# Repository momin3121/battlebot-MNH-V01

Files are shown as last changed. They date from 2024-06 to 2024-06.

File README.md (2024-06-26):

# battlebot-MNH-V01

## Table of Contents
1. [Introduction](#introduction)
2. [Design Overview](#design-overview)
3. [Weight and Dimensions](#weight-and-dimensions)
4. [Frame Construction](#frame-construction)
5. [tool System](#tool-system)
6. [Electrical Components](#electrical-components)
7. [PCB Design](#pcb-design)
8. [References](#references)

## Introduction
The "battlebot-MNH-V01" is a custom-built battle bot designed for high performance in competitive environments. This bot combines precision engineering and robust construction to achieve high mobility and effective combat capabilities.

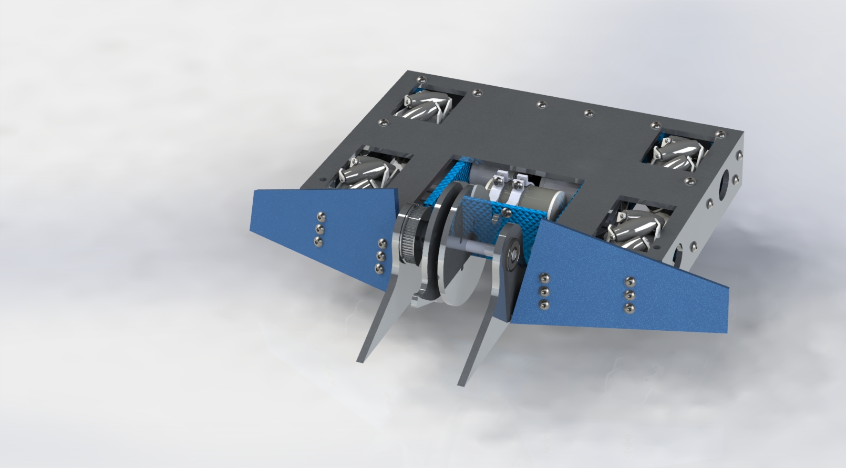
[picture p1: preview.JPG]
Battle Bot


## Design Overview
### Frame Construction
- **Material:** Aluminum
- **Construction:** The frame serves as the skeleton, providing a sturdy yet lightweight base. It includes reinforcements at critical stress points to prevent deformation during combat.
- **Benefits:** The use of aluminum and 3D-printed components allows for rapid prototyping and customization, ensuring flexibility and cost-effectiveness.

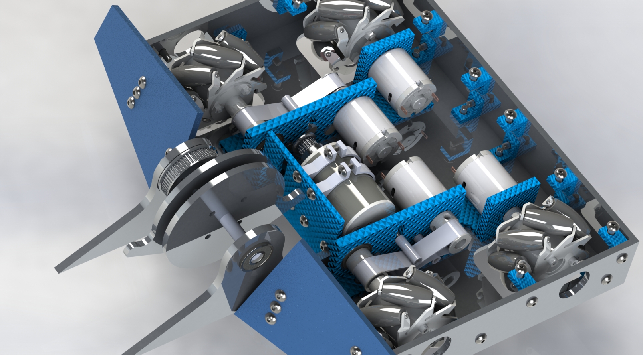
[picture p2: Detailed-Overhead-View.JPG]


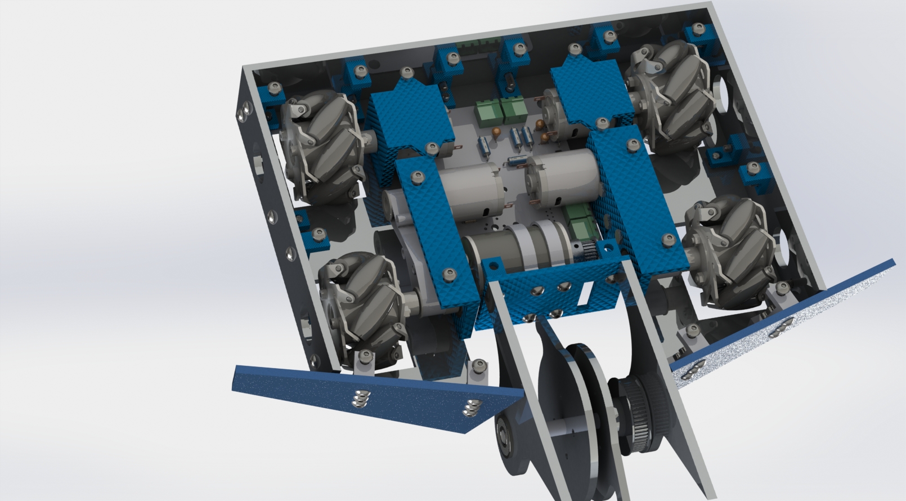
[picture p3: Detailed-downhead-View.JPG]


### Weight and Dimensions
- **Total Weight:** 3 kg
- **Overall Dimensions:** 21 cm x 20 cm

## Tool System
### Integration
- **Primary Weapon:** A centrally mounted spinning blade made from hardened steel.
- **Motor:** High-torque electric motor.
- **Specifications:**
  - **Spin Rate:** Up to 5000 RPM
  - **Impact Resistance:** Designed for high durability and easy field repairs.

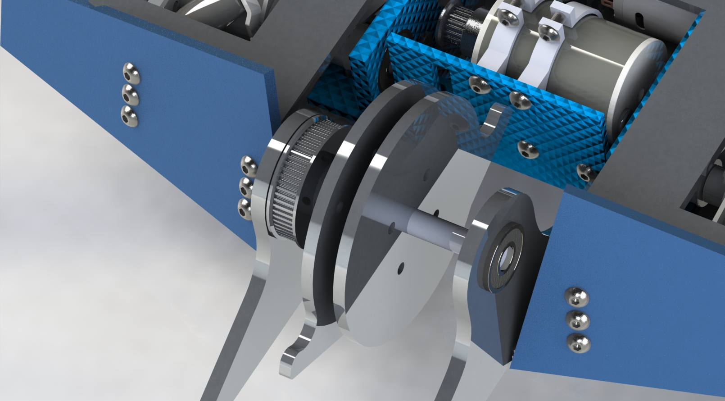
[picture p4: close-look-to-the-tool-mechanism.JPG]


## Electrical Components
### Key Components
- **DC Motor:** High Speed Electric Brush Motor (12V, 100W, 5000RPM)
- **Transmitter:** GoolRC Flysky FS-i6X Transmitter with FS-iA6B Receiver
- **Battery:** CNHL 2200mAh 3S Lipo Battery (30C, 11.1V)
- **Wheels:** Premium 97mm Mecanum Wheels
- **Controller:** ESP32-PICO-D4 microcontroller for managing motor and sensor inputs.

### Motor Drivers
- **Wheel Motors:** Dual L298HN Motor Drivers
- **Weapon Motor:** VNH2SP30 Motor Driver

## PCB Design
### Overview
The PCB (Printed Circuit Board) for the battle bot is designed to control all major functions, including motor control and sensor integration. The design focuses on robustness, efficiency, and ease of maintenance, ensuring optimal performance during competitions.

### Size and Layers
- **Dimensions:** 10 cm x 9.5 cm
- **Layers:** 2-layer design for efficient routing of power and signal traces.

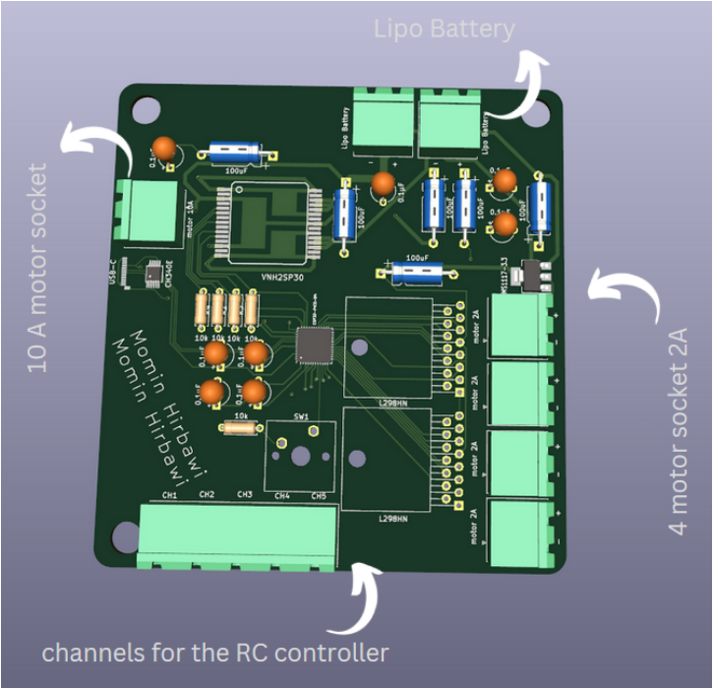
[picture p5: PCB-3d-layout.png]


### Trace Widths
- **Motor Traces:** 0.8 mm (for currents up to 2A)
- **Tool  Motor Traces:** 2.5 mm (for currents up to 10A)
- **Design Standards:** Trace widths are calculated based on IPC-2221 standards to handle the expected current loads with an allowable temperature rise of 10°C to 20°C.

### Key Components
- **Microcontroller (U3):** ESP32-PICO-D4
  - **Function:** Central processing unit that handles control logic, motor commands, and sensor inputs.
  - **Power Supply:** 3.3V provided by AMS1117-3.3 voltage regulator.
- **Motor Drivers:**
  - **L298HN (U1, U5):** Controls the four wheel motors, allowing precise movement and speed adjustments.
  - **VNH2SP30 (U2):** Manages the high-current weapon motor, providing necessary torque and speed.
- **Voltage Regulator (U6):** AMS1117-3.3
  - **Function:** Provides stable 3.3V output for low-power devices.
  - **Current Handling:** Up to 1A, supporting the microcontroller and sensors.
- **USB to Serial Converter (U4):** CH340E
  - **Function:** Enables programming and communication between the microcontroller and a computer.
- **Capacitors (C1, C10-C16):** Stabilize voltage and filter noise in the power supply.
- **Resistors (R1, R2, R3, R4, R6):** Employed for pulling up/down inputs and limiting current to protect other components.
- **Connectors (J1, J2, J3, J4, J5, J6):** Provide interfaces for external connections to motors, power sources, and other peripherals.
- **Switch (SW1):** Used to enable the microcontroller, typically controlling the power state or activation of the system.

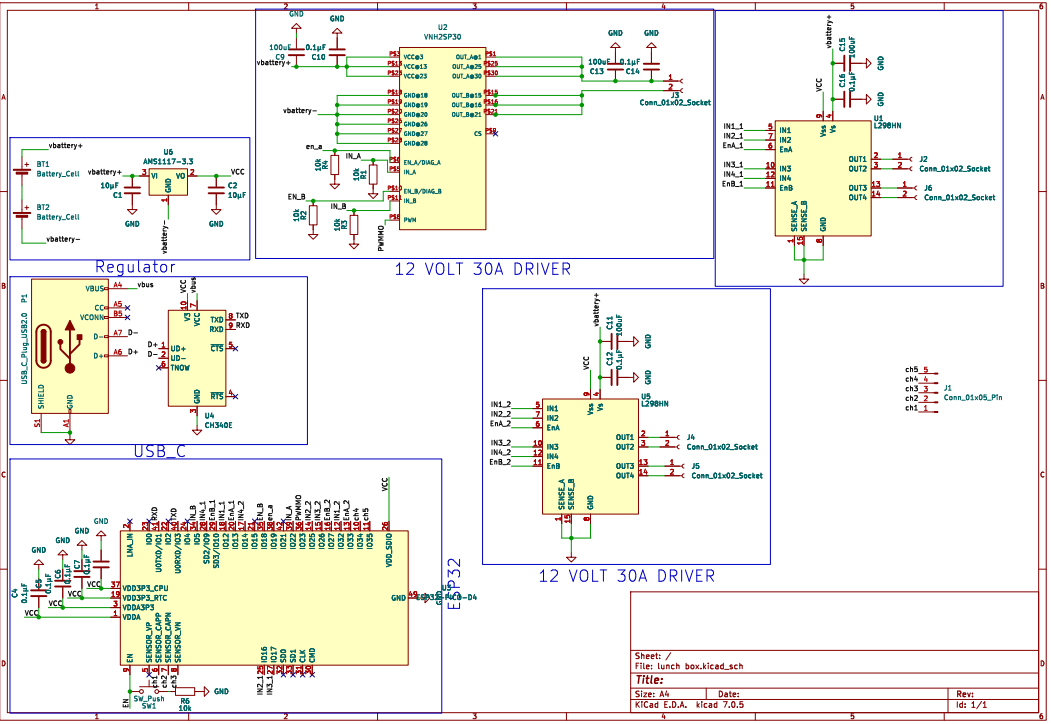
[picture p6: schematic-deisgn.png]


### Power Management
- **AMS1117-3.3 Voltage Regulator (U6):**
  - **Function:** Provides a stable 3.3V output for low-power devices.
  - **Current Handling:** Up to 1A.
  - **Integration:** Positioned near power inputs with filtering capacitors to ensure smooth operation.
- **VNH2SP30 Motor Driver:**
  - **Function:** Drives the weapon motor.
  - **Current Handling:** 30A continuous.
  - **Integration:** Includes extensive heat sinking to manage high current loads.
- **Dual L298HN Motor Drivers:**
  - **Function:** Independently controls four wheel motors.
  - **Current Handling:** 2A per channel.
  - **Integration:** Equipped with dedicated capacitors for voltage stabilization and noise filtering.

### Layout and Design Considerations
- **Trace Width:** Motor traces are designed to handle high currents without excessive heat buildup or voltage drop.
- **Via Optimization:** Used to connect traces between the top and bottom layers, enhancing electrical performance.
- **Accessibility:** All connectors and critical components are easily accessible for maintenance and troubleshooting.

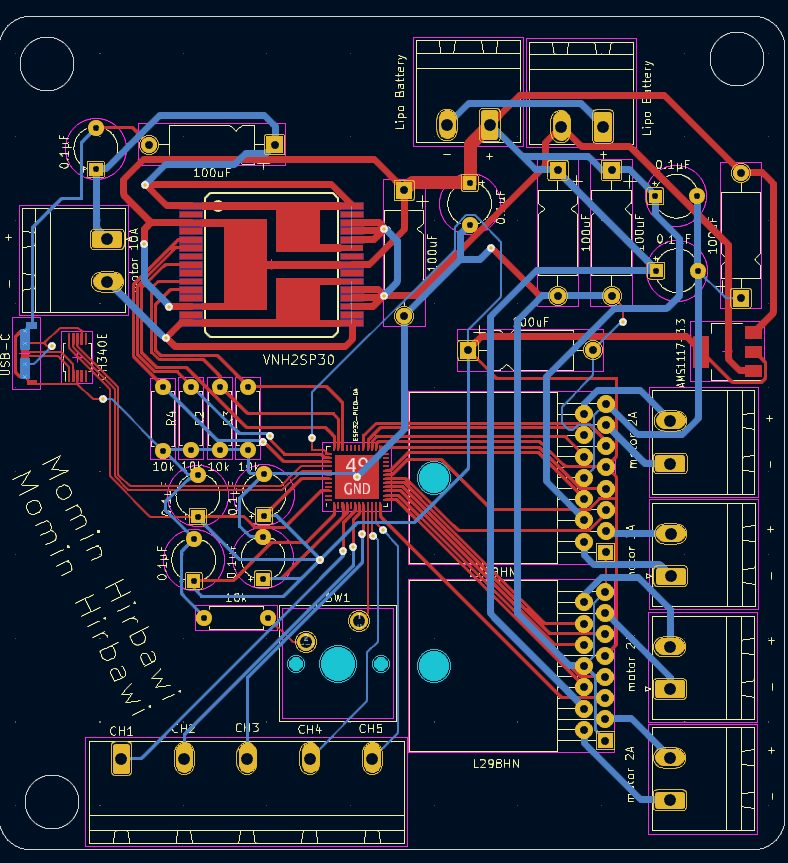
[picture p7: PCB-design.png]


## Code Example
```cpp
#include <ESP32Servo.h>
#include <FlySkyIBus.h>

const int enA1Pin = 13; 
const int in1_1Pin = 12;
const int in2_1Pin = 16;
const int enB1Pin = 10; 
const int in3_1Pin = 17;
const int in4_1Pin = 9;

const int enA2Pin = 33; 
const int in1_2Pin = 32;
const int in2_2Pin = 25;
const int enB2Pin = 27; 
const int in3_2Pin = 26;
const int in4_2Pin = 14;

const int enBPin = 35; 
const int inBPin = 5;
const int inAPin = 22;
const int pwmPin = 23;  

const int gunMotorPin = 19; 

const int enableSwitchPin = 9;

const int pwmFreq = 5000;
const int pwmResolution = 8;

const int ch1 = 0; 
const int ch2 = 1; 
const int ch3 = 2; 
const int ch4 = 3; 
const int ch5 = 4; 

void setup() {
  Serial.begin(115200);
  IBus.begin(Serial1, 115200);
  
  ledcSetup(0, pwmFreq, pwmResolution);
  ledcSetup(1, pwmFreq, pwmResolution);
  ledcSetup(2, pwmFreq, pwmResolution);
  ledcSetup(3, pwmFreq, pwmResolution);
  ledcSetup(4, pwmFreq, pwmResolution);
  ledcSetup(5, pwmFreq, pwmResolution);
  ledcSetup(6, pwmFreq, pwmResolution);

  ledcAttachPin(enA1Pin, 0);
  ledcAttachPin(enB1Pin, 1);
  ledcAttachPin(enA2Pin, 2);
  ledcAttachPin(enB2Pin, 3);
  ledcAttachPin(gunMotorPin, 4);
  ledcAttachPin(pwmPin, 5);

  pinMode(in1_1Pin, OUTPUT);
  pinMode(in2_1Pin, OUTPUT);
  pinMode(in3_1Pin, OUTPUT);
  pinMode(in4_1Pin, OUTPUT);
  pinMode(in1_2Pin, OUTPUT);
  pinMode(in2_2Pin, OUTPUT);
  pinMode(in3_2Pin, OUTPUT);
  pinMode(in4_2Pin, OUTPUT);
  pinMode(inBPin, OUTPUT);
  pinMode(inAPin, OUTPUT);
  
  pinMode(enableSwitchPin, INPUT);
}

void loop() {
  bool isEnabled = digitalRead(enableSwitchPin);

  if (isEnabled) {
    int throttle = IBus.readChannel(ch1);
    int steering = IBus.readChannel(ch2);
    int strafe = IBus.readChannel(ch3);
    int rotation = IBus.readChannel(ch4);
    int gunControl = IBus.readChannel(ch5);

    throttle = map(throttle, 1000, 2000, -255, 255);
    steering = map(steering, 1000, 2000, -255, 255);
    strafe = map(strafe, 1000, 2000, -255, 255);
    rotation = map(rotation, 1000, 2000, -255, 255);
    gunControl = map(gunControl, 1000, 2000, 0, 255);

    int motor1Speed = throttle + steering + strafe - rotation;
    int motor2Speed = throttle - steering - strafe - rotation;
    int motor3Speed = throttle - steering + strafe + rotation;
    int motor4Speed = throttle + steering - strafe + rotation;

    motor1Speed = constrain(motor1Speed, 0, 255);
    motor2Speed = constrain(motor2Speed, 0, 255);
    motor3Speed = constrain(motor3Speed, 0, 255);
    motor4Speed = constrain(motor4Speed, 0, 255);

    ledcWrite(0, motor1Speed);
    ledcWrite(1, motor2Speed);
    ledcWrite(2, motor3Speed);
    ledcWrite(3, motor4Speed);
    ledcWrite(4, gunControl);
    ledcWrite(5, gunControl);

    digitalWrite(in1_1Pin, motor1Speed > 0);
    digitalWrite(in2_1Pin, motor1Speed < 0);
    digitalWrite(in3_1Pin, motor2Speed > 0);
    digitalWrite(in4_1Pin, motor2Speed < 0);
    digitalWrite(in1_2Pin, motor3Speed > 0);
    digitalWrite(in2_2Pin, motor3Speed < 0);
    digitalWrite(inAPin, gunControl > 0);
    digitalWrite(inBPin, gunControl < 0);

    Serial.print("Throttle: "); Serial.print(throttle);
    Serial.print(" Steering: "); Serial.print(steering);
    Serial.print(" Strafe: "); Serial.print(strafe);
    Serial.print(" Rotation: "); Serial.print(rotation);
    Serial.print(" Gun: "); Serial.println(gunControl);
  } else {
    ledcWrite(0, 0);
    ledcWrite(1, 0);
    ledcWrite(2, 0);
    ledcWrite(3, 0);
    ledcWrite(4, 0);
    ledcWrite(5, 0);
  }

  delay(20);
}
```

## References
1. [High Power DC Motor](https://www.amazon.com/Power-12V-24V-Torque-Bearing-Driver/dp/B086Z47DLJ)
2. [GoolRC Flysky FS-i6X Transmitter](https://www.amazon.com/dp/B0872QHMM3)
3. [CNHL 2200mAh 3S Lipo Battery](https://www.amazon.com/CNHL-2200mAh-Battery-Airplane-Quadcopter/dp/B0BTYPT4RT)
4. [Zeberoxyz GT2 Synchronous Wheel Set](https://www.amazon.com/Zeberoxyz-Synchronous-Aluminum-Timing-20-60T-8B-6/dp/B08QZ4365D)
5. [Premium Mecanum Wheels](https://www.amazon.com/Directional-Coupling-Connector-Raspberry-Microbit/dp/B09KY6C5BG)
6. [VNH2SP30 Motor Driver](https://www.snapeda.com/parts/VNH2SP30-E/STMicroelectronics/view-part/)
7. [L298N Motor Driver](https://www.snapeda.com/parts/L298N/STMicroelectronics/view-part/)
8. [ESP32-PICO-D4 MCU](https://www.snapeda.com/parts/ESP32-PICO-D4/Espressif%20Systems/view-part/)

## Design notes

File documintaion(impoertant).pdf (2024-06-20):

Introduction and Overview

Battle Bot Design Overview

This document outlines the design and features of a custom built battle bot, designed for robust performance in competitive environments. The bot is engineered with precision, focusing on high mobility and effective combat capabilities. Its frame is constructed from high-grade aluminum, chosen for its excellent strength-to-weight ratio, enhancing the bot's agility and impact resilience.

Weight and Dimensions:

- Total Weight: 3 kg
- Material: Aluminum
- Overall Dimensions: 21 cm X 20 cm

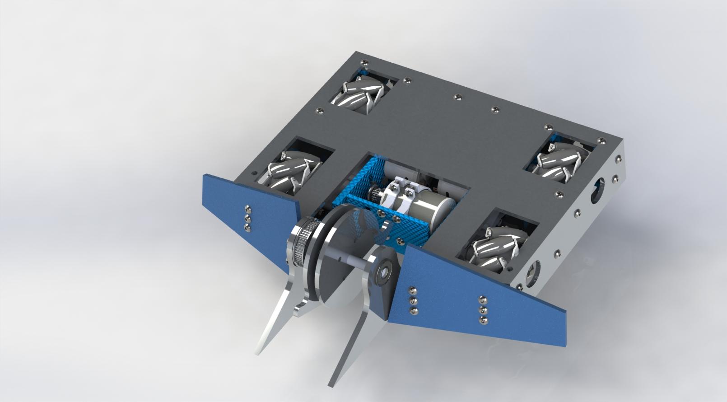
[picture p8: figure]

Frame Construction and Features

Aluminum Frame Construction

The frame of the battle bot serves as the skeleton to which all other components are attached and protected. It is crafted from aluminum, which provides a light yet sturdy base for the operational components and weaponry. The design incorporates a series of reinforcements at critical stress points to prevent deformation under combat conditions.

Materials and Fabrication

- Aluminum Frame: The primary structure is built using aluminum, known for its light weight and high strength, forming the core framework that supports all critical components and systems.
- 3D-Printed Components: Select parts of the battle bot are fabricated using advanced 3D printing technology. Materials such as ABS or PLA are chosen for these parts due to their light weight and ease of printing.

Benefits of Hybrid Construction

- Customization and Flexibility: The ability to quickly produce 3D-printed components allows for rapid prototyping and testing of parts, enabling continuous improvement and customization of the bot.
- Cost-Effective Solutions: Utilizing 3D printing reduces the cost associated with small batch production of complex parts, making it economically viable to design parts that perfectly fit the bot's needs without the need for expensive tooling or molds.

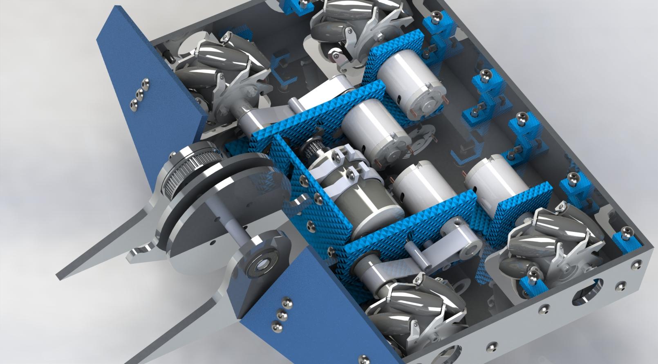
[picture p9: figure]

Figure 2: Detailed Overhead View

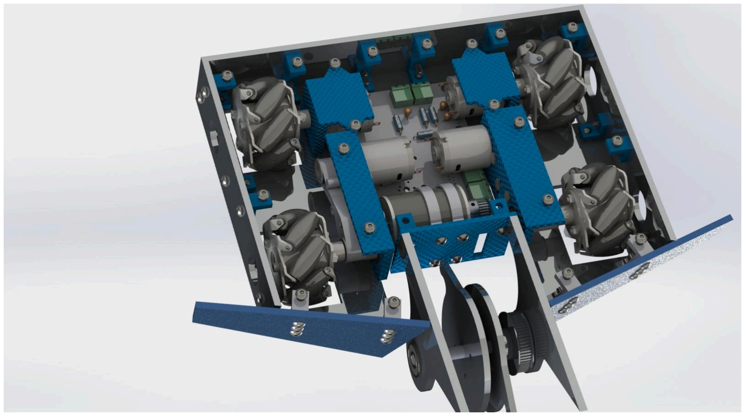
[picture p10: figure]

.Figure 3: Detailed downhead View

Tool System Details

Tool System Integration

The primary weapon system of the battle bot is a centrally mounted spinning blade, designed to deliver high-impact hits to opponents. This weapon is powered by a dedicated motor, with the blade assembly made from hardened steel to withstand the rigors of combat.

Tool Specifications:

1. Blade Material: Hardened steel
2. Motor Type: High-torque electric motor capable of rapid acceleration to maximum speed within seconds.
3. Mounting: The blade is mounted on a reinforced axle connected directly to the motor, with shock-absorbing materials used to reduce vibration and stress on the motor bearings.

Operational Capabilities:

- Spin Rate: Capable of reaching speeds up to 5000 RPM.
- Impact Resistance: Engineered to maintain functionality even after significant impacts, with easy-access features for quick field repairs.

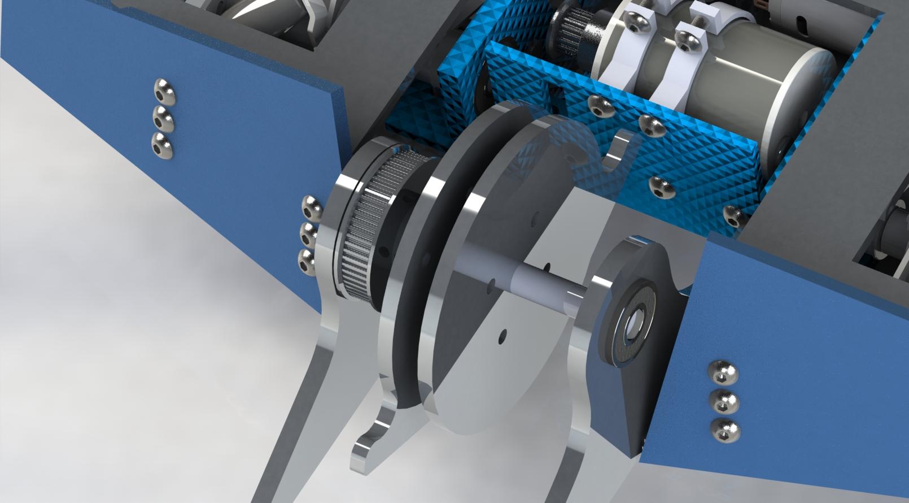
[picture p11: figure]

.Figure 4: close look to the tool mechanism

Electrical component :

The links of every component i will mention will be on the references , plus this is not the PCB components , this is just hard electrical components like motors , controller , etc …

Component | Description | Quantity | Unit Price | Total Price
DC Motor High Speed Electric Brush | 12V 100W Motor 5000RPM High Speed Electric Brush Scooter Motor R6493 RC Car | 1 | $57.39 | $57.3 9
775 High Power DC Motor | DC 12V-24V, 3200 RPM, Large Torque Motor Ball Bearing | 4 | $16.32 | $60
GoolRC Flysky FS-i6X Transmitter | 2.4GHz 10CH AFHDS 2A RC Transmitter with FS-iA6B Receiver | 1 | $46.99 | $16.0 0
CNHL 2200mAh 3S Lipo Battery | 30C 11.1V with Dean Plug, Pack of 2 | 1 | $55.00 | $55.0 0

Premium 97mm Mecanum Wheel | Omni Directional Tire with Metal 6mm Coupling | 1 Set | $43.99 | $43.9 9
Zeberoxyz GT2 Synchronous Wheel Set | 20&60 Teeth 8mm Bore with 200mm Width 6mm Belt | 1 Set | $12.89 | $12.8 9
150g 3D Printed PLA Plastic | Material for custom parts | 150g | $9.40 | $9.40
2.300 kg Aluminum Material | For structural components | 2.300 kg | $76 | $76

Table 1 : components

The PCB Design

Overview

This PCB i made is supposed to control the battle bot completely using the FS-i6X controller , by using driver ic’s for controlling the 5 motors , while the 4 wheels motors should be slower and with a less torque than the weapon motor , so i decided to use 2A DC motor for the wheels and 10A dc motor for the weapon motor , controlled by the main MUC that is (Esp32 - Peco-D4) this esp is supposed to take the signals from the 5 channels from the controller and then convert to a PWM signals to use them with the drivers

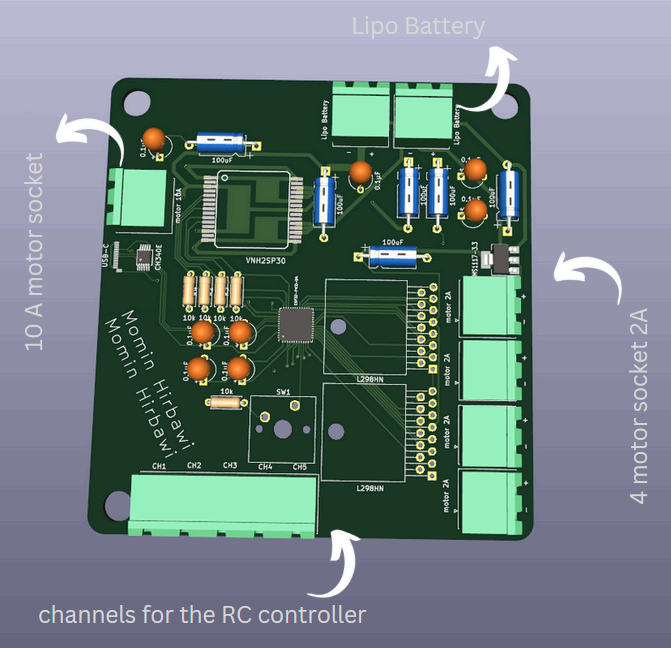
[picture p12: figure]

.Figure 5: PCB 3d layouy

Components and connections

Here is the components and its Function in this Project and the main pins wiring , also you can check the schematic design for more understanding , components in table 1 , and schematic design in figure 6

Component | Descriptio n | Function in Project | Main Pins
U3 (ESP32-PIC O-D4) | Microcontro ller | Central processing unit that handles control logic, motor commands, and sensor inputs. | VDDA, IO34-IO35, IO32-IO33, GND, additional IO pins for sensor and actuator control
U1, U5 (L298HN) | Motor Driver | Controls the four wheel motors, allowing precise movement and speed adjustments. | IN1, IN2, IN3, IN4, EnA, EnB, OUT1, OUT2, OUT3, OUT4, Vs, Vss
U2 (VNH2SP30) | Motor Driver | Manages the high-current weapon motor, providing necessary torque and speed. | IN_A, IN_B, PWM, CS, OUT_A, OUT_B, VCC, GND
U6 (AMS1117-3. 3) | Voltage Regulator | Supplies a stable 3.3V power to low-power components on the board. | VI (Input Voltage), VO (Output Voltage), GND
U4 (CH340E) | USB to Serial Converter | Enables programming and communication between the microcontroller and a computer. | TXD, RXD, VCC, GND, D+, D-, UD+
C1, C10-C16 | Capacitors | Stabilize voltage and filter noise in the power supply to various components. | - (Connected across power and ground pins of associated components)
R1, R2, R3, R4, R6 | Resistors | Employed for pulling up/down inputs and limiting current to protect other components. | - (Connected in line or across signals and power for biasing and protection)
J1, J2, J3, J4, J5, J6 | Connectors | Provide interfaces for external connections to motors, power sources, and other peripherals. | - (Pin numbers vary by connector type and usage in the design)
SW1 | Switch | Used to enable the microcontroller, typically controlling the power state or activation of the system. | - (Connected to the enable pin on the MCU)
FS-i6X Channels (CH1-CH5) | Control Channels | Interface for receiving signals from the FS-i6X transmitter, used for controlling various functions like movement and weapons. | CH1 to CH5 connected to corresponding input pins on the microcontroller for processing

Table 2 : PCB components and wiring

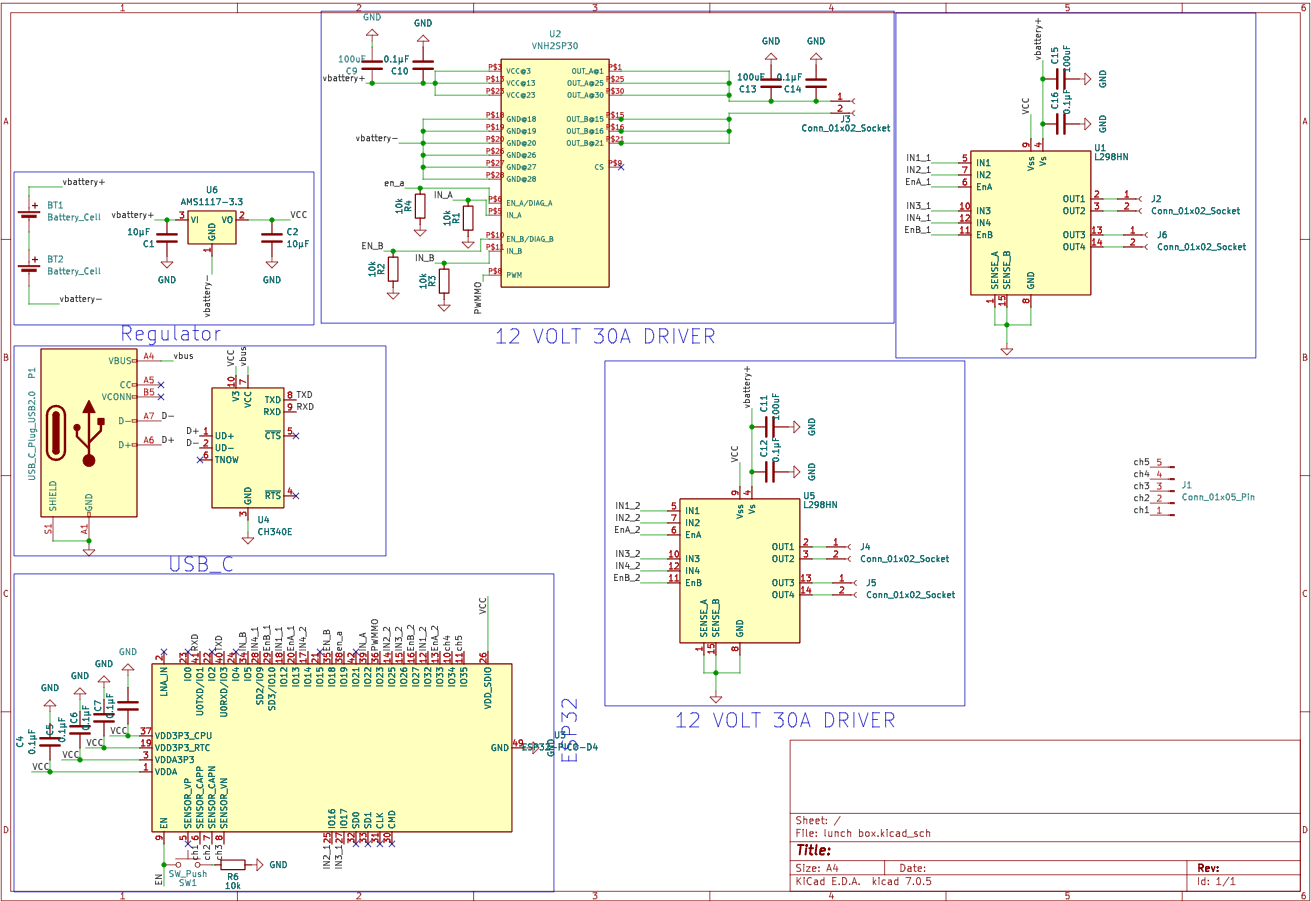
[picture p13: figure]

.Figure 6: schematic design

Power Management Components

### 1. AMS1117-3.3 Voltage Regulator (U6)

- Function: Provides stable 3.3V output for low-power devices.
- Current Handling: Up to 1A, supporting the microcontroller and sensors.
- Integration: Positioned near power inputs with filtering capacitors to ensure smooth operation.

### 2. VNH2SP30 Motor Driver

- Function: Drives the weapon motor.
- Current Handling: 30A continuous, suitable for the 10A required by the weapon.
- Integration: Includes extensive heat sinking to manage high current loads, crucial for the weapon's operation.

### 3. Dual L298HN Motor Drivers

- Function: Independently controls four wheel motors.
- Current Handling: 2A per channel, aligning with the wheel motors' 2A requirement.
- Integration: Each driver is equipped with dedicated capacitors for voltage stabilization and noise filtering.

### 4. ESP32-PICO-D4 MCU (U3)

- Function: Acts as the central processing unit, handling logic, sensor input, and motor control commands.
- Power Supply: Powered by the AMS1117-3.3 to maintain a reliable 3.3V.
- Role: Crucial for interpreting control signals and managing operational states of the battle bot.

In the PCB design for the battle bot, special attention has been paid to the trace widths to ensure they can handle the required currents without excessive heat buildup or voltage drop. For the motor traces that need to support up to 2 amps, a trace width of 0.8 mm is used. This width is calculated based on standard PCB design guidelines which recommend sufficient width to handle the current with an allowable temperature rise of 10°C to 20°C. For the more demanding application of the weapon motor, which requires up to 10 amps, the trace width is increased to 2.5 mm. This specification ensures that the traces can safely conduct higher currents, calculated using the IPC-2221 standard, which provides formulas for determining the trace width based on the expected current load and the copper thickness, typically 1 oz/ft² for standard PCBs. By adhering to these guidelines, the PCB is designed to ensure reliability and efficiency in powering both the movement and weaponry systems of the bot, crucial for optimal performance in competitive scenarios.

This PCB, measuring 10 cm by 9.5 cm, employs a concise 2-layer design, with top and bottom layers facilitating efficient routing of power and signal traces. The use of vias is optimized to connect traces between these layers effectively, enhancing the electrical performance and compactness of the design. Thicker traces on the power layer support high-current applications, vital for the motor drivers managing wheel and weapon motors. The layout also ensures that all connectors and critical components are easily accessible, which is crucial for maintenance and troubleshooting in competitive environments.

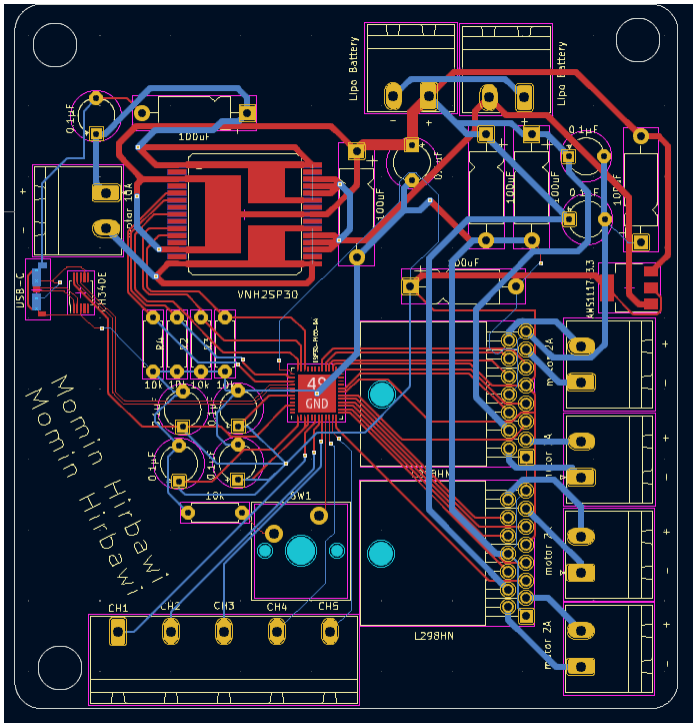
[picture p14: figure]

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
Coding

This is an arduino code because we are using peco d4 :

#include <ESP32Servo.h>

#include <FlySkyIBus.h>

const int enA1Pin = 13
const int in1_1Pin = 12;
const int in2_1Pin = 16;
const int enB1Pin = 10;
const int in3_1Pin = 17;
const int in4_1Pin = 9;

const int enA2Pin = 33;
const int in1_2Pin = 32;
const int in2_2Pin = 25;
const int enB2Pin = 27;
const int in3_2Pin = 26;
const int in4_2Pin = 14;

const int enBPin = 35;
const int inBPin = 5;
const int inAPin = 22;
const int pwmPin = 23;

const int gunMotorPin = 19;

const int enableSwitchPin = 9;

const int pwmFreq = 5000;
const int pwmResolution = 8;

const int ch1 = 0;
const int ch2 = 1;
const int ch3 = 2;
const int ch4 = 3;
const int ch5 = 4;

void setup() {
Serial.begin(115200);

IBus.begin(Serial1, 115200);

ledcSetup(0, pwmFreq, pwmResolution); ledcSetup(1, pwmFreq, pwmResolution); ledcSetup(2, pwmFreq, pwmResolution); ledcSetup(3, pwmFreq, pwmResolution); ledcSetup(4, pwmFreq, pwmResolution); ledcSetup(5, pwmFreq, pwmResolution); ledcSetup(6, pwmFreq, pwmResolution);

ledcAttachPin(enA1Pin, 0); ledcAttachPin(enB1Pin, 1); ledcAttachPin(enA2Pin, 2); ledcAttachPin(enB2Pin, 3); ledcAttachPin(gunMotorPin, 4); ledcAttachPin(pwmPin, 5);

pinMode(in1_1Pin, OUTPUT); pinMode(in2_1Pin, OUTPUT); pinMode(in3_1Pin, OUTPUT); pinMode(in4_1Pin, OUTPUT); pinMode(in1_2Pin, OUTPUT); pinMode(in2_2Pin, OUTPUT); pinMode(in3_2Pin, OUTPUT); pinMode(in4_2Pin, OUTPUT); pinMode(inBPin, OUTPUT);
pinMode(inAPin, OUTPUT);

pinMode(enableSwitchPin, INPUT); }

void loop() {

bool isEnabled = digitalRead(enableSwitchPin);

if (isEnabled) {

int throttle = IBus.readChannel(ch1); int steering = IBus.readChannel(ch2); int strafe = IBus.readChannel(ch3); int rotation = IBus.readChannel(ch4); int gunControl = IBus.readChannel(ch5);

throttle = map(throttle, 1000, 2000, -255, 255); steering = map(steering, 1000, 2000, -255, 255); strafe = map(strafe, 1000, 2000, -255, 255); rotation = map(rotation, 1000, 2000, -255, 255); gunControl = map(gunControl, 1000, 2000, 0, 255);

int motor1Speed = throttle + steering + strafe - rotation; int motor2Speed = throttle - steering - strafe - rotation; int motor3Speed = throttle - steering + strafe + rotation; int motor4Speed = throttle + steering - strafe + rotation;

motor1Speed = constrain(motor1Speed, 0, 255);
motor2Speed = constrain(motor2Speed, 0, 255);
motor3Speed = constrain(motor3Speed, 0, 255); motor4Speed = constrain(motor4Speed, 0, 255);

ledcWrite(0, motor1Speed);
ledcWrite(1, motor2Speed);
ledcWrite(2, motor3Speed); ledcWrite(3, motor4Speed); ledcWrite(4, gunControl);
ledcWrite(5, gunControl);

digitalWrite(in1_1Pin, motor1Speed > 0); digitalWrite(in2_1Pin, motor1Speed < 0); digitalWrite(in3_1Pin, motor2Speed > 0); digitalWrite(in4_1Pin, motor2Speed < 0); digitalWrite(in1_2Pin, motor3Speed > 0); digitalWrite(in2_2Pin, motor3Speed < 0); digitalWrite(in3_2Pin, motor4Speed > 0); digitalWrite(in4_2Pin, motor4Speed < 0); digitalWrite(inAPin, gunControl > 0); digitalWrite(inBPin, gunControl < 0);

Serial.print("Throttle: "); Serial.print(throttle); Serial.print(" Steering: "); Serial.print(steering); Serial.print(" Strafe: "); Serial.print(strafe); Serial.print(" Rotation: "); Serial.print(rotation); Serial.print(" Gun: "); Serial.println(gunControl); } else {

ledcWrite(0, 0);
ledcWrite(1, 0);
ledcWrite(2, 0);
ledcWrite(3, 0);
ledcWrite(4, 0);
ledcWrite(5, 0);
}

delay(20);
}

References:

1. High Power DC Motor - Detailed specifications and pricing for a high-torque motor suitable for robust applications such as battle bots. Available from Amazon. [Accessed: 2024-04-10]. Available at: https://www.amazon.com/Power-12V-24V-Torque-Bearing-Driver/dp/B086Z47DLJ
2. GoolRC Flysky FS-i6X Transmitter - A 2.4GHz 10CH transmitter with FS-iA6B Receiver for remote control applications. Available from Amazon. [Accessed: 2024-04-10]. Available at: https://www.amazon.com/dp/B0872QHMM3
3. CNHL 2200mAh 3S Lipo Battery - A 30C 11.1V lithium polymer battery with Dean Plug, commonly used for high-performance RC applications. Available from Amazon. [Accessed: 2024-04-10]. Available at: https://www.amazon.com/CNHL-2200mAh-Battery-Airplane-Quadcopter/dp/B0BTYPT4R T (https://www.amazon.com/CNHL-2200mAh-Battery-Airplane-Quadcopter/dp/B0BTYPT4RT)
4. Zeberoxyz GT2 Synchronous Wheel Set - Timing pulley and belt set for precise motion control in mechanical assemblies. Available from Amazon. [Accessed: 2024-04-10]. Available at:
https://www.amazon.com/Zeberoxyz-Synchronous-Aluminum-Timing-20-60T-8B-6/dp/B0 8QZ4365D (https://www.amazon.com/Zeberoxyz-Synchronous-Aluminum-Timing-20-60T-8B-6/dp/B08QZ4365D)
5. Premium Mecanum Wheels - Omni-directional wheels for advanced maneuverability in robotics. Available from Amazon. [Accessed: 2024-04-10]. Available at: https://www.amazon.com/Directional-Coupling-Connector-Raspberry-Microbit/dp/B09KY 6C5BG (https://www.amazon.com/Directional-Coupling-Connector-Raspberry-Microbit/dp/B09KY6C5BG)
6. STMicroelectronics VNH2SP30 Motor Driver - Specifications and datasheets for a robust motor driver. Available from SnapEDA. [Accessed: 2024-04-10]. Available at: https://www.snapeda.com/parts/VNH2SP30-E/STMicroelectronics/view-part/
7. STMicroelectronics L298N Motor Driver - Documentation for a dual full-bridge driver used for controlling DC motors. Available from SnapEDA. [Accessed: 2024-04-10]. Available at: https://www.snapeda.com/parts/L298N/STMicroelectronics/view-part/

8. Espressif Systems ESP32-PICO-D4 MCU - Technical specifications and details for the ESP32 microcontroller. Available from SnapEDA. [Accessed: 2024-04-10]. Available at: https://www.snapeda.com/parts/ESP32-PICO-D4/Espressif%20Systems/view-part/

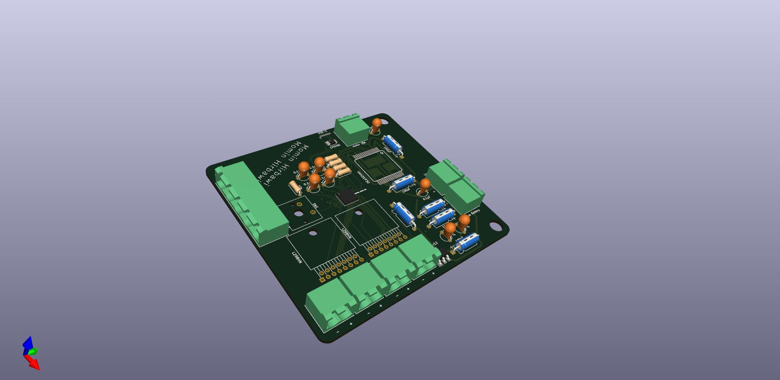
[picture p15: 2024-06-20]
PCB design/battlebot.jpg

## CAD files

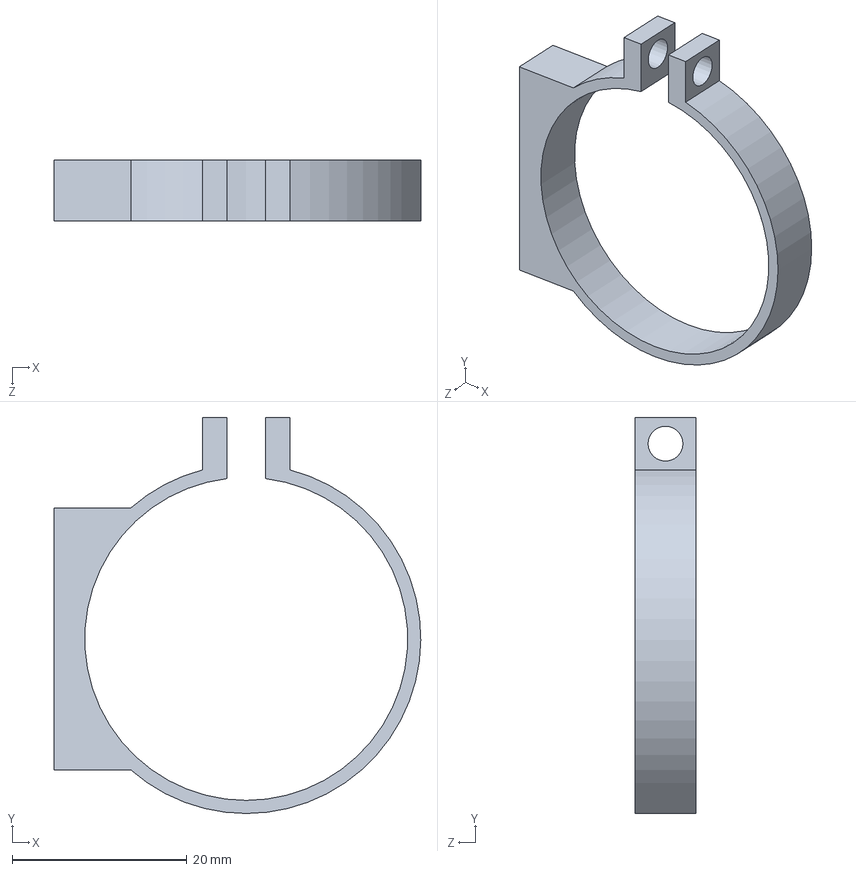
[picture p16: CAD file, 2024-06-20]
mechanical CAD design/motor.SLDPRT
42.0 x 45.4 x 7.00 mm

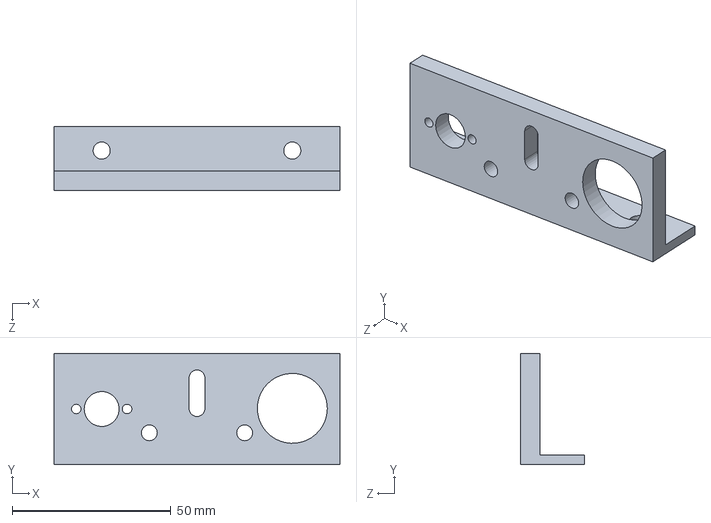
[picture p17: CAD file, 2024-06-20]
mechanical CAD design/Part2.SLDPRT
90.0 x 35.0 x 20.0 mm

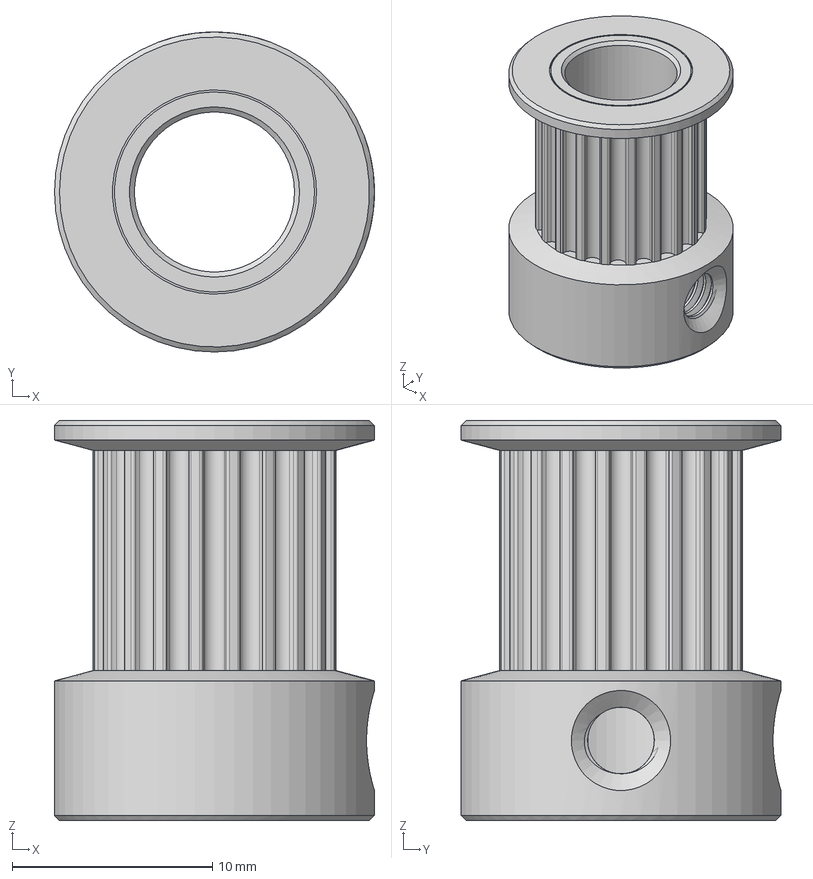
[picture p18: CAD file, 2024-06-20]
mechanical CAD design/gt2 20 tooth.step
16.0 x 16.0 x 20.0 mm

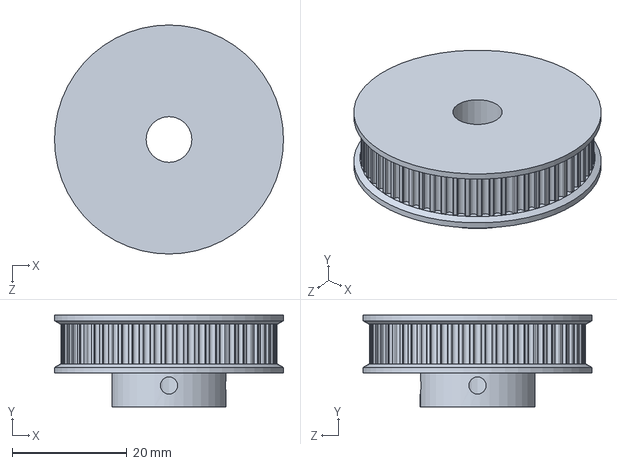
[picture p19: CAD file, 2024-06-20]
mechanical CAD design/(_82 GT2 60T b8 (6mm).SLDPRT
40.0 x 16.0 x 40.0 mm

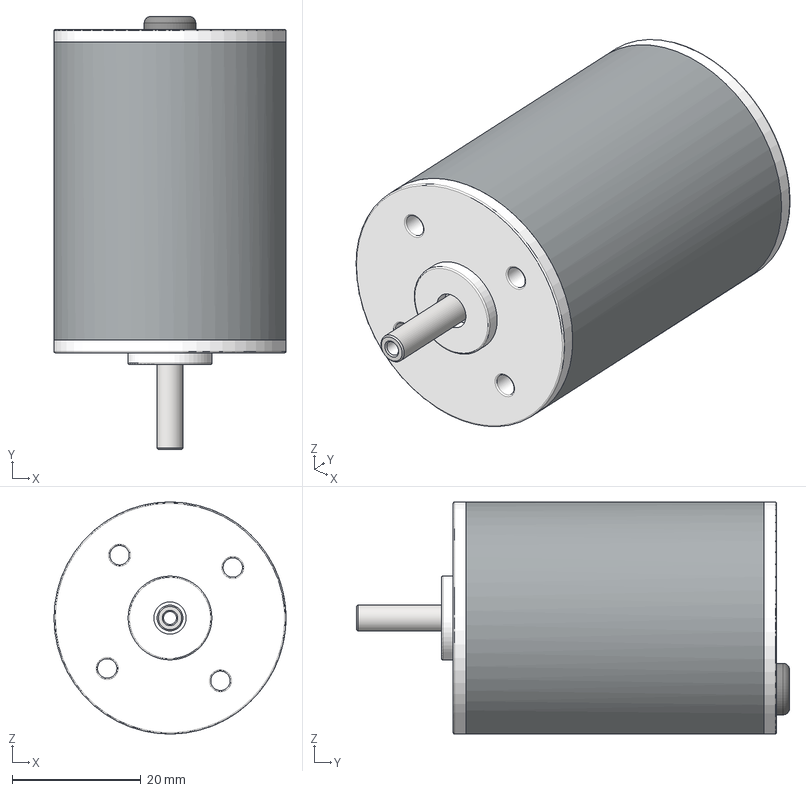
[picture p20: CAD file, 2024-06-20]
mechanical CAD design/36BLR50-24-01.stp
36.0 x 67.2 x 36.0 mm
36BLR50-24-01-P1-Back
36BLR50-24-01-P3-Front
36BLR50-24-01-P2-Middle

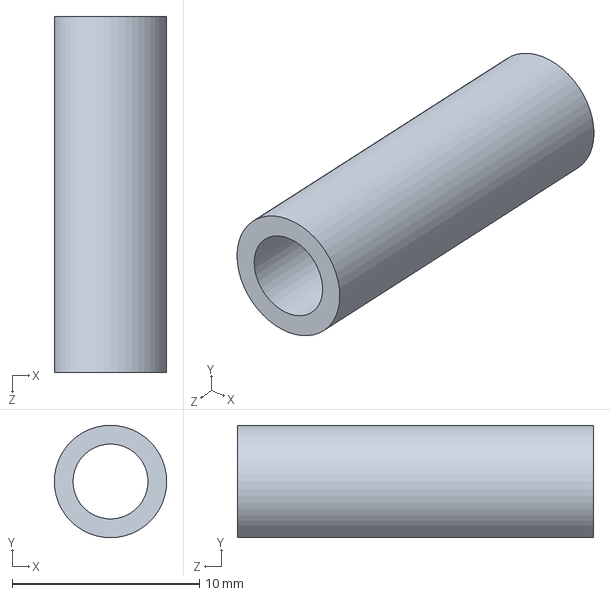
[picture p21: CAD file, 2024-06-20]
mechanical CAD design/Part5.SLDPRT
6.00 x 6.00 x 19.0 mm

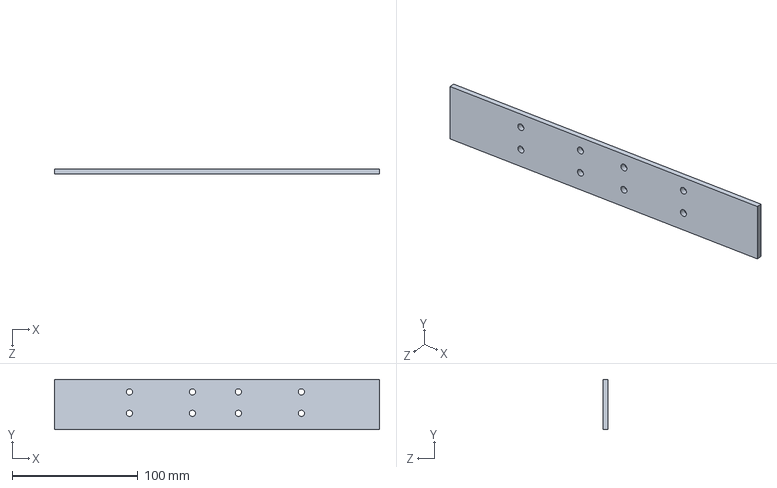
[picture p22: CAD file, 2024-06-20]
mechanical CAD design/back.SLDPRT
258.0 x 40.0 x 4.00 mm

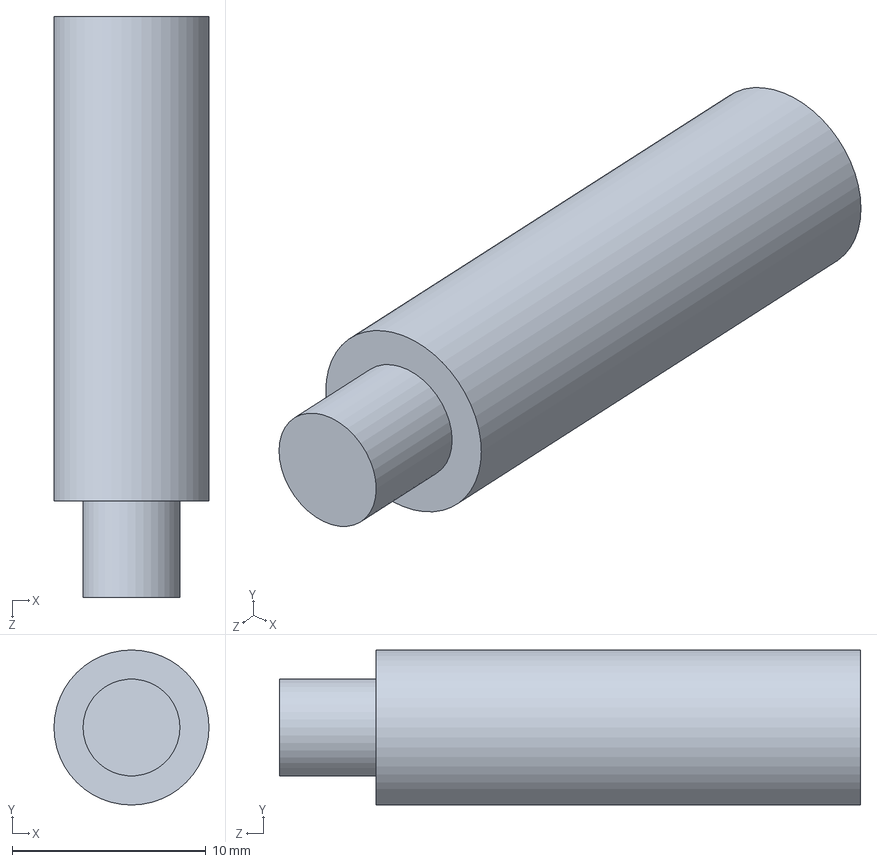
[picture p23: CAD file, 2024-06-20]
mechanical CAD design/Part4.SLDPRT
8.00 x 8.00 x 30.0 mm

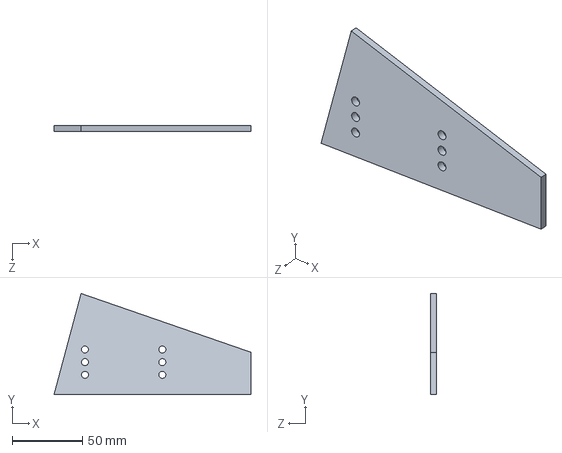
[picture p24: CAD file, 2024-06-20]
mechanical CAD design/Part6.SLDPRT
140.0 x 71.8 x 4.00 mm

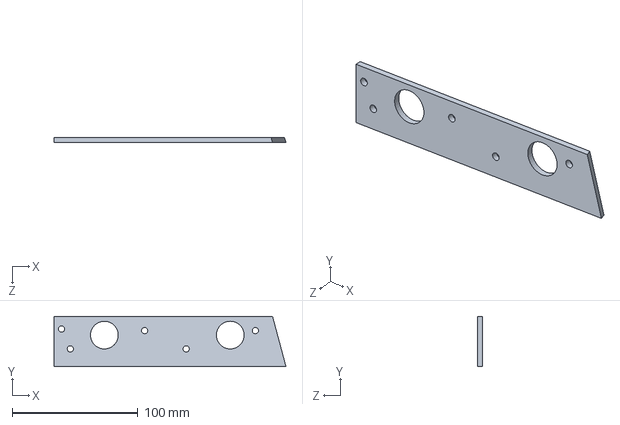
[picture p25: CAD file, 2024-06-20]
mechanical CAD design/سهيث.SLDPRT
184.3 x 39.8 x 4.00 mm

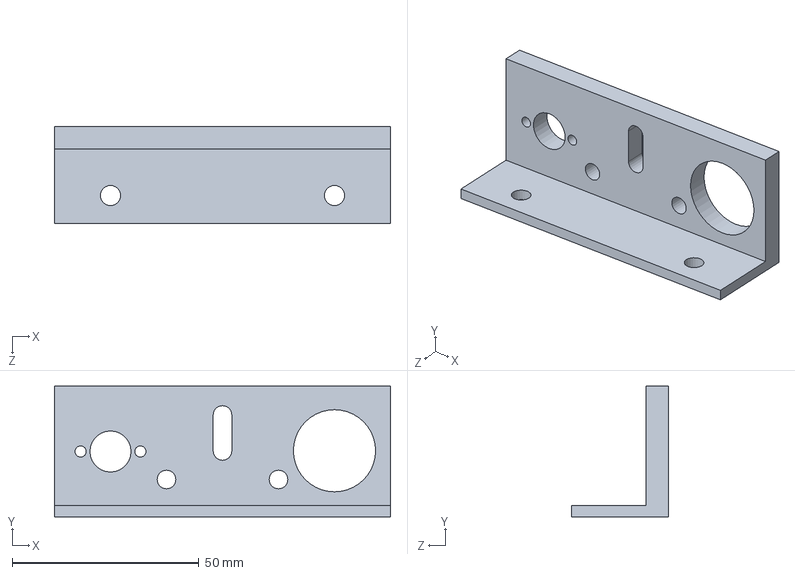
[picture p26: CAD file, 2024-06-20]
mechanical CAD design/part 2 left.SLDPRT
90.0 x 35.0 x 26.0 mm

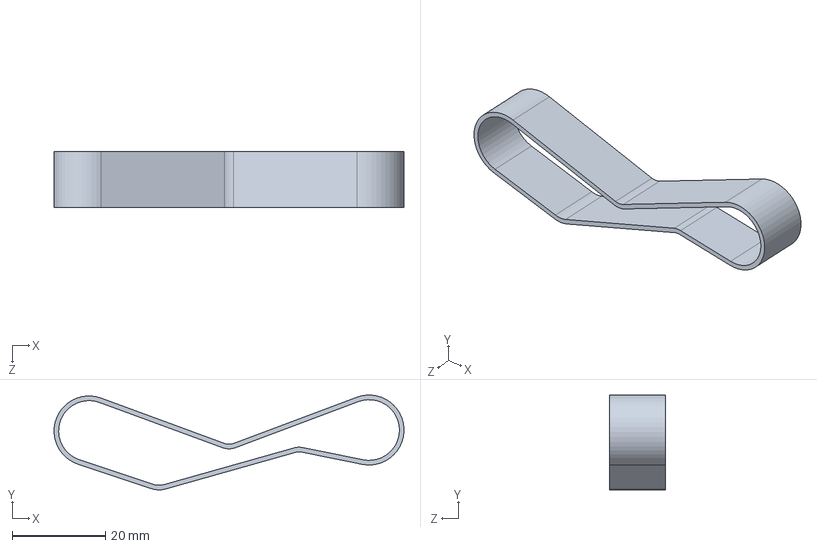
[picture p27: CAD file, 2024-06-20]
mechanical CAD design/لاثمف.SLDPRT
75.0 x 20.3 x 12.0 mm

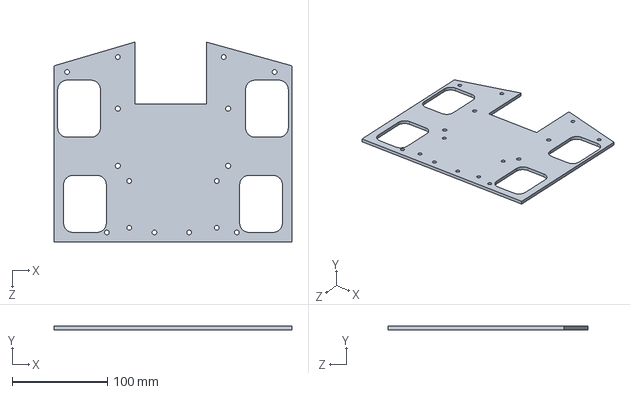
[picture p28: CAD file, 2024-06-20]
mechanical CAD design/Part1.SLDPRT
250.0 x 4.00 x 210.0 mm

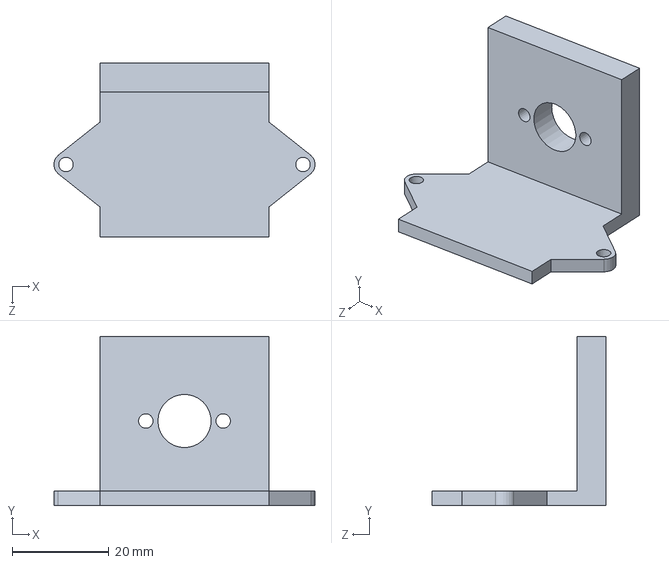
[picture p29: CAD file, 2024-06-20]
mechanical CAD design/PART 8.SLDPRT
54.0 x 35.0 x 36.0 mm

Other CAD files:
3d-deisng-ofthebot.step
mechanical CAD design/هبر 2.SLDPRT
mechanical CAD design/asd.SLDPRT
mechanical CAD design/Bearing, Sealed, 608-2RS, 22X8X7.SLDPRT
mechanical CAD design/(_82 GT2 20T b5.SLDPRT
mechanical CAD design/999.SLDPRT
mechanical CAD design/Part3.SLDPRT
mechanical CAD design/mecanumWheelHLVR.step
mechanical CAD design/motor holes.SLDPRT
mechanical CAD design/rod 8mm.SLDPRT
mechanical CAD design/لل.SLDPRT
mechanical CAD design/هبر.SLDPRT

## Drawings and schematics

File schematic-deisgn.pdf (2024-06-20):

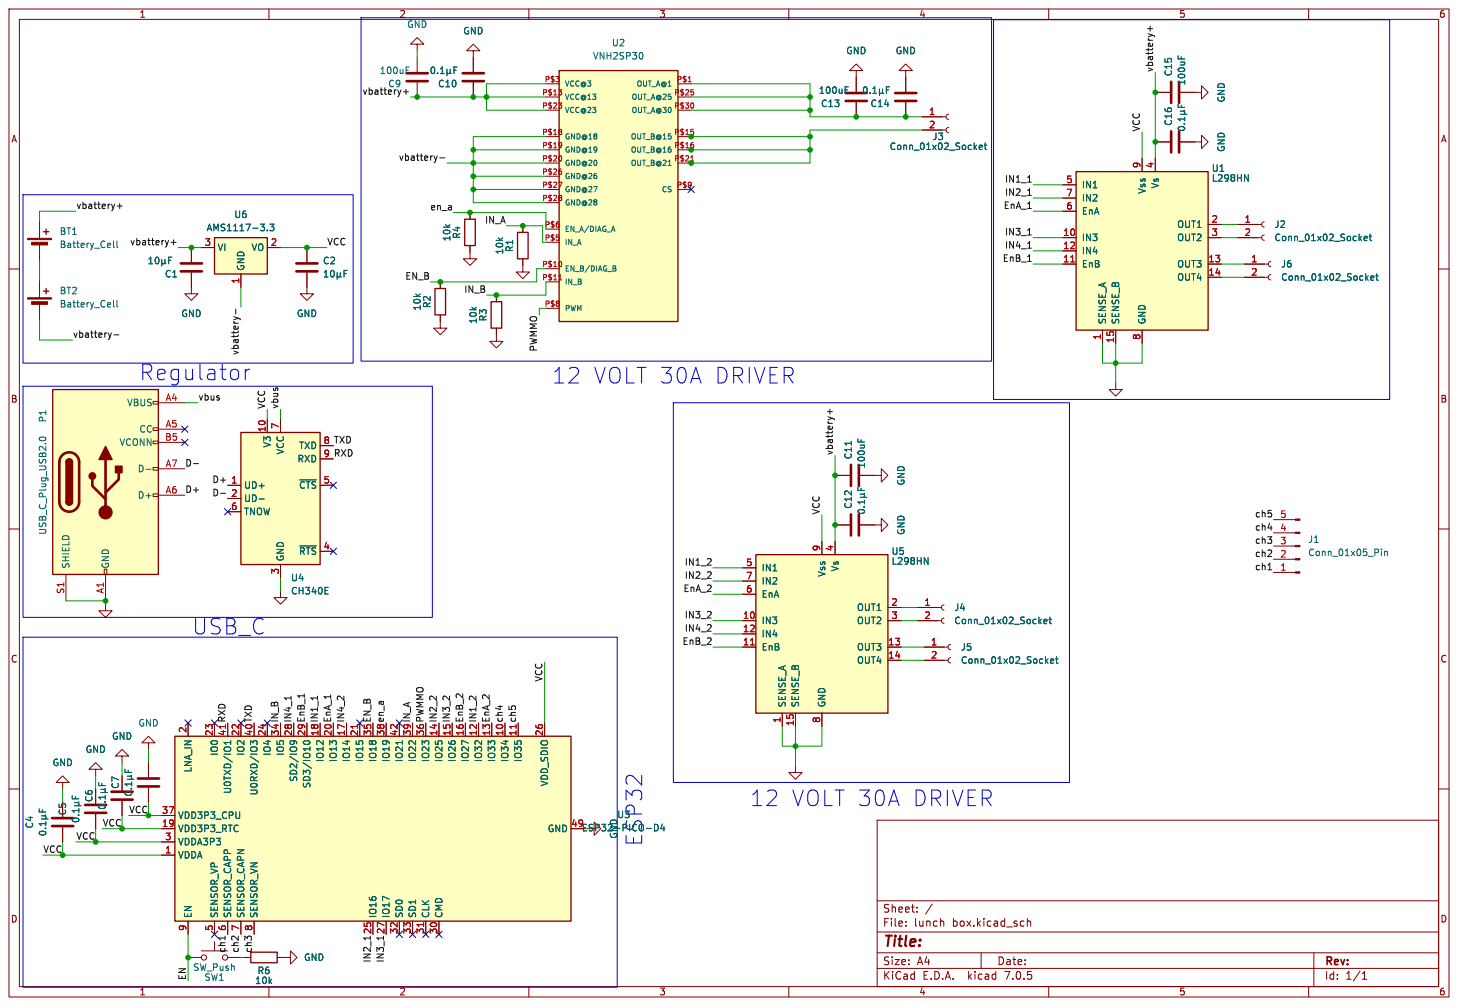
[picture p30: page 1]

IN_B P$11 VCC@13 P$13 GND@18 P$18 GND@19 P$19 GND@20 P$20 VCC@23 P$23 GND@27 P$27 GND@28 P$28 VCC@3 P$3

7 TXD 8 RXD 9 10k R310k R2 10k R110k R4 C5 þÿ0.1µFC7 þÿ0.1µF C6 þÿ0.1µFGND GND GND

1 VO 2 VI 3 GND GND

3 ~{RTS}4 ~{CTS}5 TNOW 6 VCC

8 Vss 9 GND C11 100uF GND C12 þÿ0.1µF

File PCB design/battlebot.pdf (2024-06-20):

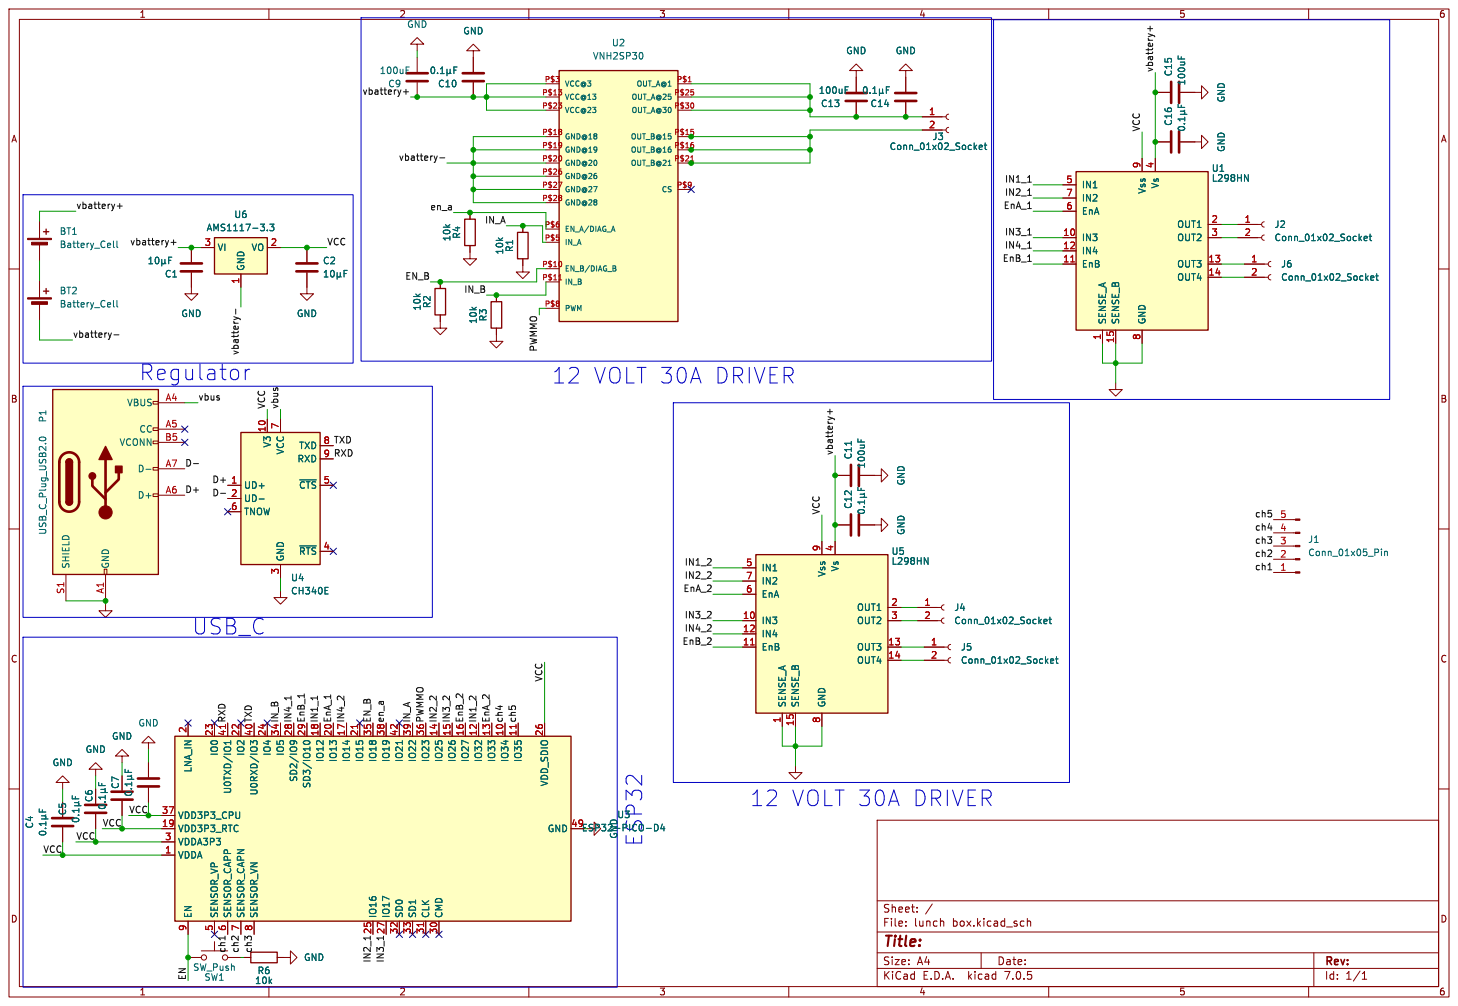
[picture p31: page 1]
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

8 Vss 9 GND GND C11 100uF C12 þÿ0.1µF U1

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

1 VO 2 VI 3 GND GND

3 ~{RTS}4 ~{CTS}5 TNOW 6 VCC

J5Conn_01x02_Socket C7 þÿ0.1µF C6 þÿ0.1µFGND GND

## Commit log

2024-06-20 new pcb
    pcb
    [(_82 GT2 20T b5.SLDPRT, (_82 GT2 60T b8 (6mm).SLDPRT, 36BLR50-24-01.stp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]
2024-06-20 Rename PCB 3d layout.png to PCB-3d-layout.png
2024-06-20 Rename PCB design .png to PCB-design.png
2024-06-20 Rename lunch box.step to 3d-deisng-ofthebot.step
    [3d-deisng-ofthebot.step]
2024-06-20 Rename schematic deisgn.pdf to schematic-deisgn.pdf
2024-06-20 Rename schematic deisgn.png to schematic-deisgn.png
